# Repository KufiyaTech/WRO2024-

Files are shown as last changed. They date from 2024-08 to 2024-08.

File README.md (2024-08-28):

# Hi, we are KufiyaTech team , representing our beloved country , Palestine!
<p align="center">
  Palestine Flag
  &nbsp;&nbsp;&nbsp;&nbsp;
  Purpose Logo
</p>

This repository contains engineering materials of a self-driven vehicle's model participating in the WRO Future Engineers competition in the season 2024.

## Content

* `t-photos` contains 2 photos of the team (an official one and one funny photo with all team members)
* `v-photos` contains 6 photos of the vehicle (from every side, from top and bottom)
* `video` contains the video.md file with the link to a video where driving demonstration exists
* `schemes` contains one or several schematic diagrams in form of JPEG, PNG or PDF of the electromechanical components illustrating all the elements (electronic components and motors) used in the vehicle and how they connect to each other.
* `src` contains code of control software for all components which were programmed to participate in the competition
* `models` is for the files for models used by 3D printers, laser cutting machines and CNC machines to produce the vehicle elements. If there is nothing to add to this location, the directory can be removed.
* `other` is for other files which can be used to understand how to prepare the vehicle for the competition. It may include documentation how to connect to a SBC/SBM and upload files there, datasets, hardware specifications, communication protocols descriptions etc. If there is nothing to add to this location, the directory can be removed.

## READ.ME table of content

1. [Project Overview](#project-overview)

   1.1. [Competition Context](#competition-context)
   
   1.2. [Team Management](#team-management)

   1.3. [Strengths and Limitations of Our Vehicle](strengths-and-limitations-of-our-vehicle)   

2. [Programming Language and Libraries](programming-language-and-libraries)
   
   2.1. [Programming Language and Libraries](programming-language-and-libraries)
 
   2.2. [Detecting Turns and Direction](#detecting-turns-and-direction)
   
   2.3. [Lap Counting Method](#lap-counting-method)
   
   2.4. [IMU-Based Steering](#imu-based-steering)
   
3. [Open Challenge](#open-challenge-algorithm)

   3.1. [Open Challenge Overview](#open-challenge-overview)

   3.2. [PID Controller](#pd-controller)
   
   3.3. [Turn Execution](#turn-execution)
   
4. [Obstacle Avoidance Round Challenge](#obstacle-avoidance-round-challenge)

   4.1. [Obstacle Challenge Overview](#obstacle-challeng-overview)

   4.2. [Pillar Detection](#pillar-detection)
    
   4.3. [Obstacle Avoidance Strategy](#obstacle-avoidance-strategy)
   
5. [Designing Process](#designing-process)

   5.1. [Steering System](#steering-system)
    
   5.2. [Differential Gear](#differential-gear)
   
   5.3. [Chassis](#chassis)
   
   5.4. [Mechanism](#mechanism)
   
   5.5. [Ackermann Steering Mechanism](#ackermann-steering-mechanism)
   
6. [Power and Sense Management](#power-and-sense-management)

   6.1. [Power Source](#power-source)
    
   6.2. [Sensors We Used and Their Functions](#sensors-we-used-and-their-functions)
   
7. [Hurdles and Challenges](#hurdles-and-challenges)

   7.1. [Designing Process Challenges](#designing-process-challenges)
    
   7.2. [Sensor and Coding Challenges](#sensor-and-coding-challenges)

   7.3. [Mechanical Challenges](mechanical-challenges)

8. [Future Work](#future-work)

9. [Appendices](#appendices)

   9.1. [Datasheets and Specifications](#datasheets-and-specifications)
      
   9.2. [References](#references)

 10. [Reflections and Gratitude](#reflections-and-gratitude)

## Project Overview

This project has been in development for nearly three months to participate in the WRO Future Engineers 2024 competition. The competition challenges teams to develop a self-driving car capable of autonomously completing two rounds on a designated track. You can view the competition track here.

A self-driving car is a vehicle designed to operate with minimal to no human intervention. For this project, our focus has been on key areas such as sensor fusion, computer vision, and advanced control systems, which are critical to the vehicle's performance.

The project is aimed at engineering students, robotics enthusiasts, and anyone interested in autonomous vehicle technologies, especially those within the 14-19 age group. It incorporates a range of technologies, including C++, Arduino, and AI cameras for computer vision tasks.

The vehicle’s architecture features an Arduino-based control system, integrated with various sensors such as an IMU, ultrasonic sensors, and a camera. These components work together to achieve the desired level of autonomy.

To meet the competition’s demands, our approach integrates sophisticated hardware and software solutions. We’ve developed robust algorithms that enable the car to make autonomous decisions based on real-time sensor data. This not only demonstrates the car’s ability to avoid obstacles but also highlights its precision in following designated paths. The project spans multiple engineering disciplines, including electronics, mechanics, and software development, making it a comprehensive showcase of modern engineering applied to robotics.

### 1.1 Competition Context

The WRO Future Engineers 2024 competition challenges teams to design and develop autonomous vehicles capable of navigating a predefined course while executing specific tasks. This competition is structured across multiple rounds, including a practice round, two qualification rounds, and a final round, each progressively testing the vehicle's capabilities.

Participants must engineer their vehicles to handle complex challenges such as lane following, obstacle detection, and precise turning. The competition track is designed with a variety of elements, including straight paths, curves, and intersections, which the vehicle must navigate autonomously without human intervention. 

Scoring is based on the vehicle's ability to complete the course with accuracy and efficiency, with additional points awarded for successful task execution and speed.

For detailed competition rules, please refer to the official WRO Future Engineers 2024 guidelines: [WRO Future Engineers 2024 Rules](https://wro-association.org/wp-content/uploads/WRO-2024-Future-Engineers-Self-Driving-Cars-General-Rules.pdf)

### 1.2 Team Management

Our project is the result of a collaborative effort by a skilled and dedicated team, each member bringing unique expertise to the table. We are students of **Purpose Robotics Academy**, located in Ramallah, Palestine, where we have gained valuable skills in robotics and technology. You can learn more about the academy through their [website](https://purpose.ps/) and [Facebook page](https://www.facebook.com/PurposeEdu/).

- **Sara Jawaada**: As the lead designer, Sara was instrumental in overseeing the entire design process, ensuring that the physical and conceptual elements of the project were seamlessly integrated. Additionally, she played a key role in software development, contributing to both the architecture and implementation of core functionalities.

  **Contact Information**:  
  **Email**: [sarajawaada906@gmail.com](mailto:sarajawaada906@gmail.com)

- **Amro Duhaidi**: Amro led the technical implementation of the software, with a particular focus on sensor integration and system wiring. His expertise in coding and hardware interfacing was crucial in developing the responsive and reliable behavior of the robot, ensuring that all sensors were effectively utilized in the project's logic.

  **Contact Information**:  
  **Email**: [amro.duaidi@gmail.com](mailto:amro.duaidi@gmail.com)

**Project Supervisor**

We would like to extend our deepest gratitude to our mentor and coach, **Eng. Mohammad Muamar**. A distinguished engineer and graduate of Palestine Polytechnic University in Hebron, Eng. Muamar has been instrumental in guiding our team through every step of this competition. His dedication, expertise, and unwavering support have been invaluable to our progress and success.

As students of esteemed professors who are proud holders of Palestinian degrees with expertise of global standards, we are honored to have Eng. Muamar as our mentor. His commitment to excellence and his belief in our potential have profoundly shaped our approach and achievements in this project.

**Contact Information**:
- **Email**: [moh.mummar@gmail.com](mailto:moh.mummar@gmail.com)

**KufiyaTech Team's Social Accounts**

Stay connected with our team and follow our journey through our official social media channels. Explore more about our work, updates, and behind-the-scenes moments by visiting our link tree:

- **KufiyaTech Social Accounts**: [https://linktr.ee/kufiyatech](https://linktr.ee/kufiyatech)
- 
### 1.3. Vehicle Strengths and Limitations

**Strengths:**

- **Chassis and Mechanism:** We designed the chassis ourselves and incorporated a mechanism built using the LEGO kit. This approach not only ensures that the vehicle meets the competition’s specific requirements but also provides us with valuable hands-on experience in both design and engineering.

- **Lightweight and Fast**

**Limitations:**

- **Size**

- **Mechanism Precision**

**Vehicle Dimensions:**

-**Vehicle weight:** 980 gm

- **Without Camera:**
  - **Length:** 26 cm
  - **Width:** 16.7 cm
  - **Height:** 10.5 cm

- **With Camera:**
  - **Length:** 23 cm
  - **Width:** 16.7 cm
  - **Height:** 18 cm

## 2. Programming Language and Libraries

 **Programming Language**: **C++**

- **Why C++?**:

- We chose C++ because it is well-supported by the Arduino IDE and provides robust library support, making it an ideal choice for our project.
  
We leveraged several libraries to implement the functionalities required for our robot:

- **`Wire.h`**: Facilitates I2C communication between the Arduino and various sensors, such as the IMU, allowing us to efficiently gather and process sensor data.

- **`Servo.h`**: Used for controlling the servo motors, particularly in steering and managing precise movements.

- **`Pixy2.h`**: Handles communication with the Pixy2 camera sensor, which is crucial for visual tracking and object recognition tasks.

- **`MPU6050.h`**: Provides functions to interface with the MPU6050 IMU sensor, enabling accurate detection of orientation, acceleration, and gyroscopic data to manage the robot's movement and stability.

These libraries, combined with the robustness of C++, provide the necessary tools to implement the complex control logic required by our autonomous vehicle.

### 2.4 Detecting Turns and Direction

**Problem Statement:**
In the WRO Future Engineers competition, the direction of the car's movement is not predetermined; it can be either clockwise or counterclockwise. This unpredictability introduces an additional layer of complexity, particularly when the car needs to execute precise U-turns at specific points on the track. The challenge is to accurately detect the required direction and execute the turn with precision.

**First Solution: Using the TCS3200 Color Sensor**

One approach to solving this problem involved the use of the TCS3200 color sensor to detect the color-coded lines on the track that indicate the direction of the car's movement.

- **Color Detection:** The TCS3200 sensor was programmed to recognize specific colors on the track. An orange line signals that the car should move in a clockwise direction, while a blue line indicates a counterclockwise movement.

- **Controlled Turning:** Upon detecting a color, the car was instructed to turn at a specific angle. The turning angle was precisely controlled using an Inertial Measurement Unit (IMU), ensuring that the turn was executed accurately and consistently, regardless of external factors like speed or track conditions.

- **Code Implementation:** The process was automated through predefined functions such as `detectOrangeLine` and `detectBlueLine`, which triggered the appropriate turning actions based on the color detected.

This method provided a clear and direct way to determine the car's direction based on visual cues from the track, leveraging the IMU for precision in turning.

**Second Solution: Using Three Ultrasonic Sensors**

An alternative approach utilized three ultrasonic sensors to determine the direction of the car's movement based on distance measurements:

- **Direction Determination:** The ultrasonic sensors were positioned to monitor distances on the left, right, and front of the car. When the car reached a point where it needed to turn, the direction was determined by comparing the distances detected by the sensors:
  - If the distance measured by the right sensor was greater than that of the left sensor, the car would turn clockwise.
  - Conversely, if the left distance was greater, the car would turn counterclockwise.

- **Front Sensor Trigger:** Additionally, the front ultrasonic sensor played a crucial role by detecting when the car was approximately 50 cm away from an obstacle or turning point. This detection served as a cue for the car to initiate the turn.

This method relied on spatial awareness and distance measurement, allowing the car to make decisions based on its surroundings without relying on visual markers.

<p align="center">
  Turn Detection Logic
</p>
<p align="center">
  <em>Figure 1: Illustration of the turn detection logic using ultrasonic sensors.</em>
</p>

As illustrated above, when the car reaches the lines where it needs to turn, the direction of the turn is determined by the distance sensors. If the sensors detect that the right distance is greater than the left distance, the car should turn clockwise. If the left distance is greater than the right distance, the car will move counterclockwise. When the front sensor detects that the distance is approximately 50 cm, it indicates that the car should turn.

**Final Decision: Implementing the Ultrasonic Sensor-Based Approach**

After careful consideration, the "Kufiya" team decided to implement the second method using ultrasonic sensors. This decision was driven by numerous challenges encountered with the first method involving the color sensor. Despite spending two months attempting to fine-tune the color sensor, we faced significant issues with its accuracy, particularly in varying lighting conditions and with precise color recognition.

The sensor's inconsistent performance led to unreliable direction detection, which was critical for the success of our project. These difficulties prompted us to shift our focus to the ultrasonic sensor-based approach, which provided a more reliable and adaptable solution for determining the car's movement direction and executing precise turns.

### 2.5 Lap Counting Method

**Problem Statement:**
The goal is to implement a lap counting mechanism for an autonomous vehicle (or RC car) that accurately counts the number of laps the vehicle completes on a designated track. A key requirement is that after completing exactly three laps, the vehicle must automatically stop.

#### 1. Color Sensor-Based Detection

**Overview:**
The first method involves utilizing a color sensor (TCS3200) to detect specific markers placed on the track. This technique leverages the sensor's ability to identify distinct colors, allowing it to register a lap each time the sensor passes over a designated colored marker.

**Principle:**
- The color sensor is calibrated to recognize a specific color distinct from the track's surface.
- When the sensor detects this color, it triggers a signal to increment the lap count.

**Why Do We Not Recommend This Method?**

- **Accuracy Issues:** Despite extensive efforts, the color sensor consistently struggled to provide accurate readings, particularly with the color orange. Ambient lighting conditions significantly affected the sensor's performance, even with a custom shield.
- **Programming Challenges:** Programming the sensor to reliably identify the target color was difficult, especially given the high speed of the vehicle, which impaired the sensor’s ability to detect and register the color in real-time.
- **Unreliable Performance:** The sensor's inconsistent and imprecise measurements, especially under dynamic conditions, made it an unsuitable choice for our project. This unreliability led us to explore alternative lap counting methods.

#### 2.5 Loop-Based Counting with Ultrasonic Sensor and IMU

**Overview:**
The second method utilizes a software-based loop counter that increments the lap count each time a specific condition within the code is met. In our approach, the robot detects the completion of a lap using an ultrasonic sensor. When the sensor detects that the distance to a specific point or object is less than 50 cm, the robot recognizes this as an indicator to begin a new lap. The robot’s steering is controlled by an IMU (Inertial Measurement Unit), which ensures precise navigation during turns.

**Principle:**
- The loop-based method is implemented by continuously monitoring the distance using the ultrasonic sensor.
- When the sensor detects that the distance has decreased below 50 cm, the robot initiates a turning maneuver, guided by the IMU.
- This detection and turning process is managed within a loop structure in the code, specifically within a `while` loop that executes as long as the distance remains below 60 cm.
- Each time this condition is met, the program increments the lap count, allowing for accurate tracking of the robot’s laps.

**Advantages of This Method:**
- **Reliability:** This method provides more reliable lap counting, unaffected by external factors like ambient light.
- **Precision:** The IMU ensures precise control of the vehicle’s steering, contributing to accurate lap counting

---

### 2.6 IMU-Based Steering

**Overview:**

In our autonomous vehicle, precise steering control is essential for navigating the course accurately. We implemented an IMU-based steering mechanism to achieve this. The IMU (Inertial Measurement Unit) provides real-time data about the vehicle’s angular velocity, which is critical for calculating the yaw angle (the vehicle’s turning angle) and ensuring stable and accurate steering.

**Understanding the IMU:**

An IMU (Inertial Measurement Unit) is a sensor device that combines multiple sensing components, usually a 3-axis accelerometer and a 3-axis gyroscope. These sensors work together to track the vehicle's motion and orientation in three-dimensional space.

- **Accelerometer**: Measures the acceleration along the X, Y, and Z axes. It helps in determining the tilt of the vehicle.
- **Gyroscope**: Measures the angular velocity (the rate of rotation) around the X, Y, and Z axes. It is crucial for determining the vehicle's rotational motion, especially the yaw angle.

**The X, Y, and Z Axes:**

Understanding the axes is essential for interpreting the data provided by the IMU:

- **X-Axis**: Represents the roll, or the tilting motion of the vehicle from side to side.
- **Y-Axis**: Represents the pitch, or the tilting motion of the vehicle from front to back.
- **Z-Axis**: Represents the yaw, or the rotational movement of the vehicle around the vertical axis. This axis is crucial for steering, as it defines the direction the vehicle is facing.

<p align="center">
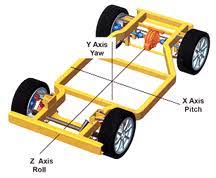
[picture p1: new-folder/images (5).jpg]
  
</p>
<p align="center"><em>*Figure 2: The X, Y, and Z axes relative to the vehicle.

**Calculating the Yaw Angle:**

The yaw angle (\(\theta_z\)) is a measure of the vehicle's rotation around the Z-axis. The gyroscope within the IMU provides angular velocity data along this axis, which tells us how quickly the vehicle is rotating.

To determine the vehicle's orientation or heading, we calculate the yaw angle by integrating the angular velocity over time. The yaw angle changes based on the rate of rotation, and by continuously updating this value, we can keep track of the vehicle's direction.

The equation used to calculate the yaw angle is:

<p align="center">
  Equation
</p>

<p align="center"><em>

Where:
- (theta_z) is the current yaw angle.
- (theta_{z, \text{previous}}\) is the yaw angle from the previous time step.
- ({gyro}_z\) is the angular velocity around the Z-axis (provided by the gyroscope).
- ({gyro\_z\_offset}\) is the gyroscope offset, calculated during calibration to correct any drift.
- (Delta t) is the time elapsed between the current and previous readings.

**Importance of Gyro Offset:**

The gyroscope offset (\(\text{gyro\_z\_offset}\)) is critical because gyroscopes can have slight errors or biases over time, known as drift. By calculating and subtracting this offset, we ensure that the yaw angle calculation is accurate and doesn't gradually deviate from the true value.

**PID Control for Steering:**

To maintain or correct the vehicle’s path, we implemented a PID (Proportional-Integral-Derivative) controller. The PID controller adjusts the steering angle based on the difference between the target yaw angle and the current yaw angle. This ensures smooth and stable steering.

## 3.Open Challenge 

### 3.1 Open Challenge Overview

The vehicle must complete three (3) laps on the track with random placements of the inside track walls

**Round objectives:**

•	Moving between the internal and external wall.

•	Turning the  car when detecting the lines . 

•	Detecting blue and orange lines on the mat.

•	Counting the laps.

•	The car stops after 3 laps. 

**Round constraints:**

•	Time.

•	The car Turning in the correct angle.

•	The direction of the car's movement is random.

•	The position from which the car starts moving is random.

•	The distance between the internal and external wall is random.

### 3.2 PID Controller

**Overview:**

The **PID (Proportional-Integral-Derivative) controller** is a widely used control loop feedback mechanism in industrial and automation systems. It is designed to continuously adjust a process to maintain the desired output, known as the setpoint, by minimizing the error between the setpoint and the actual process variable.

The PID controller operates by combining three distinct control actions:

1. **Proportional (P):** Reacts to the current error by producing an output that is proportional to the error. It provides immediate corrective action but can lead to overshoot if used alone.
2. **Integral (I):** Addresses accumulated past errors by summing them over time, helping to eliminate steady-state errors.
3. **Derivative (D):** Predicts future errors by considering the rate of change of the error, helping to reduce overshoot and oscillations.

The control signal, which is sent to the servo motor, is calculated as:

<p align="center">
  Equation 2
</p>

<p align="center"><em>

<div align="center">
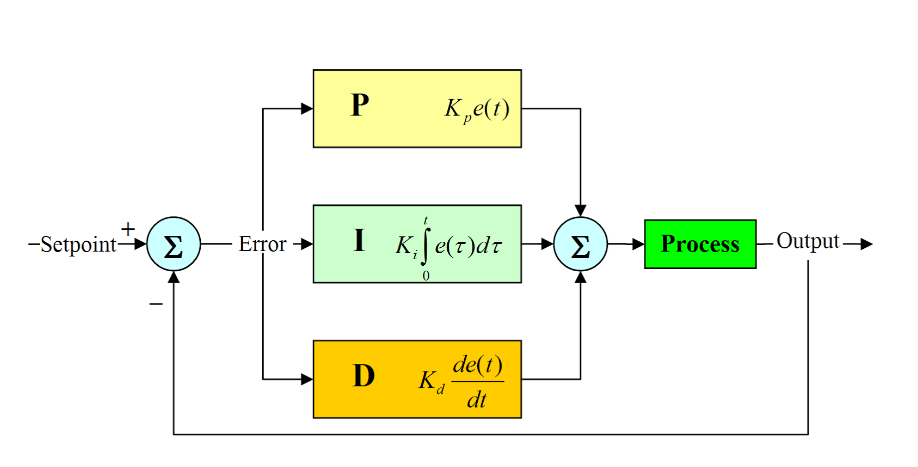
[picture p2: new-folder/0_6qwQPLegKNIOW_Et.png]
  
  <p><em>Figure 3: PID Control System for Steering.</em></p>
</div>

### Code Implementation:

The code implementation ties together the IMU readings, yaw angle calculation, and PID control to manage the vehicle's steering:

**Key Equations:**

**Proportional Term:**  

<div align="center">
  
  <p><em>Figure 4: The Proportional Term equation, where \( e(t) \) is the current error and \( K_p \) is the proportional gain.</em></p>
</div>

**Integral Term:**  

<div align="center">
  
  <p><em>Figure 2: The Integral Term equation, which sums past errors over time, multiplied by the integral gain \( K_i \).</em></p>
</div>

Here, `integral` is the accumulated error over time.

 **Derivative Term:**

<div align="center">
  
  <p><em>Figure 5: The Derivative Term equation, which considers the rate of change of the error, multiplied by the derivative gain \( K_d \).</em></p>
</div>

 **Combined PID Control:**

<div align="center">
  
  <p><em>Figure 6: The Combined PID Control equation that sums all three components to generate the control output.</em></p>
</div>

In our code:

- `error` is the difference between the target yaw angle (`targetYawAngle`) and the current yaw angle (`yaw_angle`).
- `integral` accumulates the `error` over time.
- `derivative` is the rate of change of the `error`.
- `controlSignal` is the final output applied to the servo motor, calculated using the combined PID equation.

- 
**Implementation in Our Project:**

In our autonomous vehicle project, the PID controller is utilized to maintain the vehicle's yaw angle, ensuring that it follows the desired path accurately.

**How It Works:**

1. **Initialization:**
   - The vehicle's IMU (Inertial Measurement Unit) is initialized to provide real-time gyroscope data. This data is crucial for determining the yaw angle, which represents the vehicle's direction.

2. **Error Calculation:**
   - The yaw angle error is calculated by comparing the current yaw angle with the target yaw angle. This error is then used to compute the necessary adjustments.
     ```cpp
     error = yaw_angle - targetYawAngle;
     ```

3. **PID Calculations:**
   - **Proportional:** The error is multiplied by the proportional gain \( K_p \) to determine the immediate correction.
   - **Integral:** The sum of past errors is calculated and multiplied by the integral gain \( K_i \), contributing to the correction by addressing accumulated deviations.
   - **Derivative:** The rate of change of the error is determined and multiplied by the derivative gain \( K_d \), providing a predictive adjustment to smooth out the response.
     ```cpp
     integral += error * (currentTime - previousTime);
     derivative = (error - previousError) / (currentTime - previousTime);
     ```

4. **Control Signal Generation:**
   - The control signal, which adjusts the servo motor's angle, is computed as the sum of the proportional, integral, and derivative components:
     ```cpp
     controlSignal = Kp * error + Ki * integral + Kd * derivative;
     float t = controlSignal + 90;
     t = constrain(t, 40, 140);
     myServo.write(int(t));
     ```

5. **Practical Application:**
   - As the vehicle moves, the PID controller continuously adjusts the steering to keep the vehicle on course. If the vehicle deviates, the controller calculates the necessary steering corrections to bring it back on track smoothly.

```cpp
#include <Wire.h>
#include <MPU6050.h>
#include <Servo.h>

MPU6050 mpu;
Servo myServo;
int16_t gz;
float yaw_angle = 0, gyro_z_offset = 0;
float Kp = 2, Ki = 0.001, Kd = 0.5;
float error, integral = 0, derivative, controlSignal;
unsigned long previousTime, currentTime;

void setup() {
    Serial.begin(9600);
    Wire.begin();
    mpu.initialize();
    myServo.attach(SERVO_PIN);
    Serial.println("Calibrating gyro...");
    calculateGyroDrift();
    Serial.println("Done Calibrating");
    previousTime = millis();
}

void loop() {
    MoveFWwithGyro();
}

void MoveFWwithGyro() {
    currentTime = millis();
    float elapsed_time = (currentTime - previousTime) / 1000.0;
    previousTime = currentTime;

    gz = mpu.getRotationZ() - gyro_z_offset;
    float gyro_z = gz / 131.0;
    yaw_angle += gyro_z * elapsed_time;

    error = targetYawAngle - yaw_angle;
    integral += error * elapsed_time;
    derivative = (error - previousError) / elapsed_time;
    controlSignal = Kp * error + Ki * integral + Kd * derivative;
    controlSignal = constrain(controlSignal, 40, 140);
    myServo.write(int(controlSignal));

    previousError = error;
    Serial.print("Yaw Angle: "); Serial.println(yaw_angle);
}

void calculateGyroDrift() {
    for (int i = 0; i < 2000; i++) {
        gyro_z_offset += mpu.getRotationZ();
        delay(2);
    }
    gyro_z_offset /= 2000;
}
```

**Explanation of the Code:**

1. **Setup:**
   - The IMU and servo motor are initialized. The gyroscope is calibrated to calculate the `gyro_z_offset`.
   
2. **Main Loop:**
   - The function `MoveFWwithGyro()` is called continuously. It reads the gyroscope data, calculates the yaw angle, and then computes the control signal using the PID controller.
   
3. **Yaw Angle Calculation:**
   - The yaw angle is updated based on the angular velocity around the Z-axis, factoring in the time elapsed since the last update.
   
4. **PID Control:**
   - The error between the desired and actual yaw angle is calculated. The control signal, which adjusts the steering angle, is then determined by the PID formula. This control signal is sent to the servo motor to adjust the vehicle's direction.

**Conclusion:**

The PID controller is a critical component in our system, ensuring the vehicle maintains a stable and accurate trajectory. By balancing the immediate response (P), accumulated error correction (I), and predictive adjustment (D), the PID controller allows for precise control of the vehicle's movements, even in dynamic and challenging environments.

### 3.2 Turn Execution

To ensure the car turns efficiently when reaching U-turns, we applied precise control for accurate turn execution.

**Turn Execution Logic**

The process of executing turns integrates several key components to achieve precision and reliability:

1. **Ultrasonic Sensors**:
   - Our vehicle is equipped with ultrasonic sensors on the left, right, and front sides, which continuously provide distance measurements from walls.
   - These sensors play a crucial role in determining the need and direction of the turn by comparing the distances detected on either side of the vehicle.

2. **Gyroscope (Inertial Measurement Unit - MPU6050)**:
   - The IMU sensor provides real-time data on the vehicle's yaw angle, which is the rotational angle around the vertical axis.
   - This data is essential for calculating the vehicle's current orientation and ensuring that turns are executed with high angular precision.

3. **PID Controller**:
   - To ensure smooth and controlled turning, a Proportional-Integral-Derivative (PID) controller is used.
   - The PID controller calculates the difference between the current yaw angle and the target yaw angle, adjusting the steering motor accordingly.
   - This control mechanism is critical in avoiding overshooting or undershooting the turn, maintaining the vehicle's intended path.

**Code Implementation for Turn Execution**

The following code snippet demonstrates the logic and functions used to manage turn execution:

```cpp
void MoveFWwithGyro() {
    long current_time = millis();
    currentTime = millis();
    float elapsed_time = (current_time - previous_time) / 1000.0;
    previous_time = current_time;

    gz = mpu.getRotationZ();
    gz -= gyro_z_offset;
    float gyro_z = gz / 131.0;
    yaw_angle += gyro_z * elapsed_time;

    error = yaw_angle - targetYawAngle;
    integral += error * elapsed_time;
    derivative = (error - previousError) / elapsed_time;
    controlSignal = Kp * error + Ki * integral + Kd * derivative;
    float t = controlSignal + 90;

    t = constrain(t, 50, 130);
    myServo.write(int(t));

    previousError = error;
    previousTime = currentTime;

    Serial.print("Yaw Angle: "); Serial.println(yaw_angle);
}

void TurnRight() {
    targetYawAngle -= 89; // Adjust this value for sharper or softer turns
    while (yaw_angle > targetYawAngle + 5) {
        MoveFWwithGyro();
    }
}

void TurnLeft() {
    targetYawAngle += 89; // Adjust this value for sharper or softer turns
    while (yaw_angle < targetYawAngle - 5) {
        MoveFWwithGyro();
    }
}
```

**Overview of Operations**

**Turn Initiation:**

- The robot initiates a turn  when the track requires a change in direction, such as a U-turn.
- The turn direction is determined by comparing the distance readings from the left and right sensors, ensuring that the vehicle turns in the optimal direction.

**Turn Execution:**

- The `MoveFWwithGyro()` function is the core routine that continuously monitors the vehicle's orientation and adjusts the steering angle during the turn.
- Depending on the required turn direction, the `TurnRight()` or `TurnLeft()` function sets the target yaw angle and engages the PID-controlled steering adjustments until the vehicle reaches the desired orientation.
- The PID controller plays a critical role in minimizing error and stabilizing the vehicle's movement during and after the turn.
- 
**Post-Turn Adjustment:**

- Once the vehicle achieves the required yaw angle, the steering mechanism returns the vehicle to a straight path, allowing it to continue its course efficiently.
- The combination of real-time sensor data and the PID control algorithm ensures that the vehicle resumes its path without deviation or drift.

By integrating advanced sensor data and control algorithms, our vehicle is capable of executing turns with high precision, a crucial capability for successfully navigating the competition track.

## 4. Obstacle Avoidance Round Challenge

**Obstacle Challenge Overview**

In this challenge, the autonomous vehicle must complete three laps on a track where green and red traffic signs are randomly placed. These signs instruct the vehicle on which side of the lane it should follow:

- **Red Pillar**: Indicates that the vehicle must stay on the right side of the lane.
- **Green Pillar**: Indicates that the vehicle must stay on the left side of the lane.

At the end of the second lap, the final traffic sign will determine the direction for the third lap:

- **Green Traffic Sign**: The vehicle continues the third lap in the same direction.
- **Red Traffic Sign**: The vehicle must turn around and complete the third lap in the opposite direction.

The vehicle is required not to move any of the traffic signs during the course. After completing all three laps, the vehicle must find the designated parking area and perform parallel parking.

**Important Note**: The initial driving direction (clockwise or counterclockwise) will change in different rounds of the challenge. Both the starting position of the vehicle and the number and location of traffic signs are randomly set before each round begins.

**Round Objectives**

- **Traffic Sign Response**: 
  - **Red Pillar**: Steer right.
  - **Green Pillar**: Steer left.

- **Third Lap Direction**:
  - **Green Sign**: Continue in the same direction.
  - **Red Sign**: Reverse direction.

- **Turn Execution**: 
  - Turn when reaching the U-TURN.

- **Lane Keeping**: 
  - Stay centered between the walls.

- **Final Task**: 
  - Perform parallel parking after completing three laps.

**Round constraints:**

- Randomized Pillar Placement
- Randomized Pillar Count
- Randomized Driving Direction
- Randomized Starting Position
- Randomized Parking Lot Location
.

### 4.2 Pillar detection 

**Pixy2 Camera Overview**

Pixy2 is a compact, fast, and versatile vision sensor specifically designed for robotics applications. Like its predecessor, Pixy2 can quickly learn to detect objects that you teach it, simply by pressing a button. It also features advanced algorithms for detecting and tracking lines, which is particularly useful for line-following robots. These algorithms can even detect intersections and recognize "road signs" that can instruct your robot to perform actions like turning left, turning right, or slowing down. All of this is processed at 60 frames-per-second, ensuring that your robot can operate at high speeds while still accurately detecting its environment.

For more details, you can visit the [Pixy2 Official Website](https://pixycam.com/pixy2/) and check out this [informative video](https://www.youtube.com/watch?v=391dXDjqzXA&t=1675s) on how to use Pixy2. Additionally, if you want to learn more about teaching Pixy2 to recognize objects, you can refer to the [Pixy2 Documentation](https://docs.pixycam.com/wiki/doku.php?id=wiki:v2:teach_pixy_an_object_2).

**Example of Pixy2 in Action**

We configured the Pixy2 camera using the PixyMon application to detect green and red pillars. Below are images captured from the PixyMon interface, showing the successful detection of these objects:

<div align="center">
  <table>
    <tr>
      <td align="center" style="padding: 10px;">
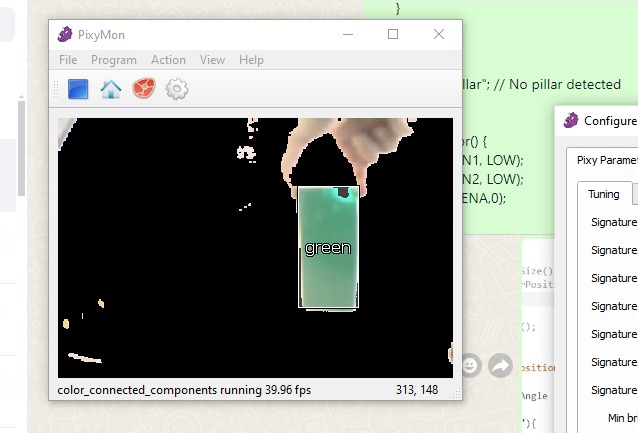
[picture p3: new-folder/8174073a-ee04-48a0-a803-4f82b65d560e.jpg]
Pixy2 Detecting Green Object
        <br>
        <figcaption><strong>Figure 7:</strong> Pixy2 camera detecting a green object.</figcaption>
      </td>
      <td align="center" style="padding: 10px;">
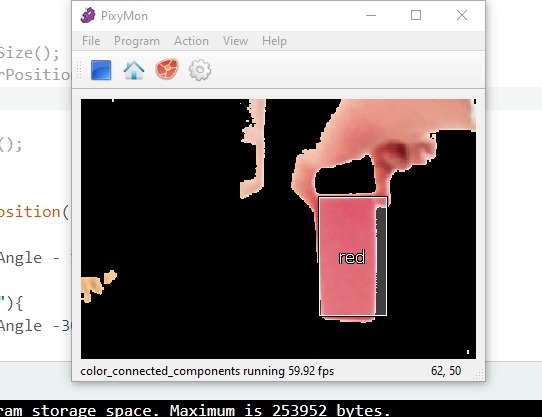
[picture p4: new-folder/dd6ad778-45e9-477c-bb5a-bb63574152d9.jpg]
Pixy2 Detecting Red Object
        <br>
        <figcaption><strong>Figure 8:</strong> Pixy2 camera detecting a red object.</figcaption>
      </td>
    </tr>
  </table>
</div>

### 4.3 Obstacle Avoidance Strategy

In the Obstacle Avoidance Round, the vehicle employs the Pixy2 camera to detect pillars on the track. The logic behind the code ensures that the vehicle reacts appropriately based on the detected pillars’ size and color:

- **Pillar Detection**: The Pixy2 camera continuously scans for pillars along the vehicle’s path. Once a pillar is detected, the system measures its size to determine if it is relevant for further action.

- **Size Check**: If the detected pillar's size is greater than 1000, the vehicle proceeds to analyze its color. This size threshold helps filter out irrelevant objects or distant pillars that do not require an immediate response.

- **Color-Based Reaction**:
  - **Green Pillar**: If the pillar is green, the vehicle is programmed to make a left turn. This is achieved by adjusting the servo motor's angle to steer the vehicle in the correct direction.
  - **Red Pillar**: Conversely, if the pillar is red, the vehicle makes a right turn by similarly adjusting the servo motor's angle.

This process ensures that the vehicle navigates the track effectively by responding to the obstacles in its path with precise and controlled movements.

### 5. Designing Process

Building an RC car for the WRO Future Engineers competition from scratch has been a significant challenge, especially since it was our first time designing a robot. Although using a kit would have been an easier option, we were committed to building our own robot, which left us with no other options. As we began gathering the necessary components, our focus was on identifying the exact mechanisms required for our RC car. Our goal was to solve the challenges presented in the two competition rounds as effectively and simply as possible. The design of our robot has evolved over time, and here is how our designs have developed throughout this journey:

#### 5.1 Steering System

- *First Design:*
  - Our initial steering system was functional, but we faced challenges in supporting and securing all the components on top of it.
 <p align="center">
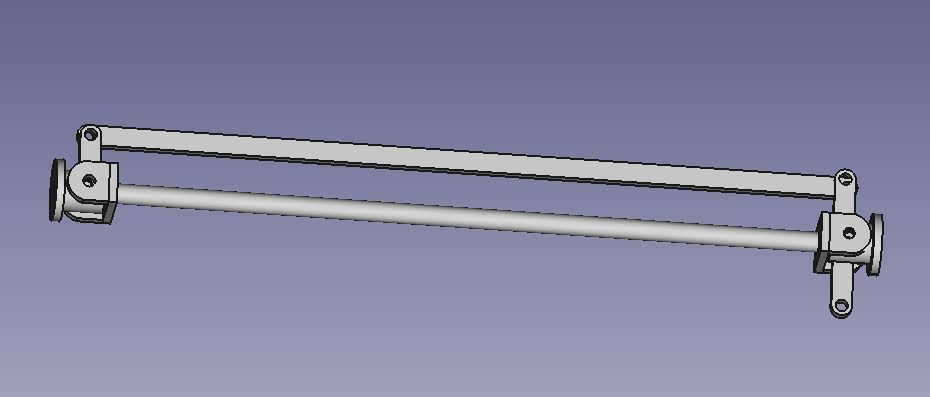
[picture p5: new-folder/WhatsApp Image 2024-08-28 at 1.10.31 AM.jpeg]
First Steering System Design
  
</p>
<p align="center"><em>Figure 9: First Steering System Design</em></p>

- *Second Design:*
  - This design proved to be a better choice initially, but it was based on ready-to-print files sourced from the internet. This presented a dilemma: adhere to the predefined dimensions that we couldn't alter, or undertake the challenge of designing it entirely from scratch.
  - *Link 1:* [3D Printed RC Car with Brushless Motor](https://cults3d.com/en/3d-model/gadget/3d-printed-rc-car-with-brushless-motor-lee3d999)

- *Third Design:*
  - Unlike our previous designs, this iteration did not require 3D printing because we utilized the EV3 LEGO kit for the mechanism. This approach saved us time and effort, providing the flexibility to modify and control it easily. The LEGO kit offered a reliable steering solution that we could test quickly, contrasting with the longer process required by our previous designs.

#### 5.2 Differential Gear System

- *First Design:*
  - Our initial choice was similar to the second steering system option in terms of using ready-to-print files. However, we encountered familiar challenges, compounded by an additional difficulty: the inability to locate suitable shafts or bearings within our allotted timeframe.
 
  - *Link 2:* [3D Printed RC Car with Brushless Motor](https://cults3d.com/en/3d-model/gadget/3d-printed-rc-car-with-brushless-motor-lee3d999)

- *Second Design:*
  - In this design, we chose to utilize the EV3 LEGO system to construct our steering mechanism, marking a departure from our previous approaches. This choice offered the same advantages as our third steering system design, particularly in terms of ease of management and reliability.

#### 5.3 Chassis Design Process

- *First Design:*
  - Our initial design phase was the most time-consuming. Being our first attempt, we struggled with defining the shape of our robot and determining how it would accommodate all intended components, including five ultrasonic sensors. This constrained our design options significantly. Our primary objective was to create a chassis capable of housing all components, prioritizing functionality over minimizing size. We positioned the camera at the rear without adhering to standard engineering principles. Initially, we planned to use a 3D printer for manufacturing.
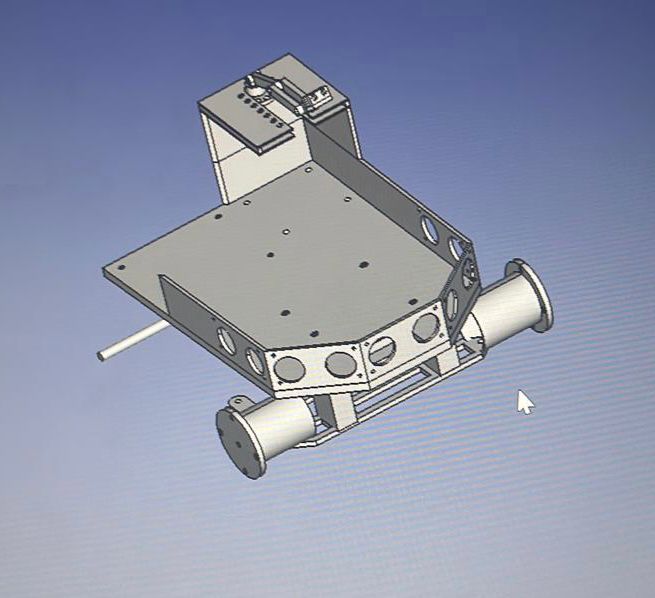
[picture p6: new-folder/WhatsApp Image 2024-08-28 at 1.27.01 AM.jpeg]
First Chassis Design
  -

  - **Figure 11**: First Chassis Design

- *Second Design:*
  - This was the first design we brought to life by printing it using a 3D printer. This design incorporated our chosen mechanism, but upon completion, we discovered it was too compact to meet our established standards.
 <p align="center">
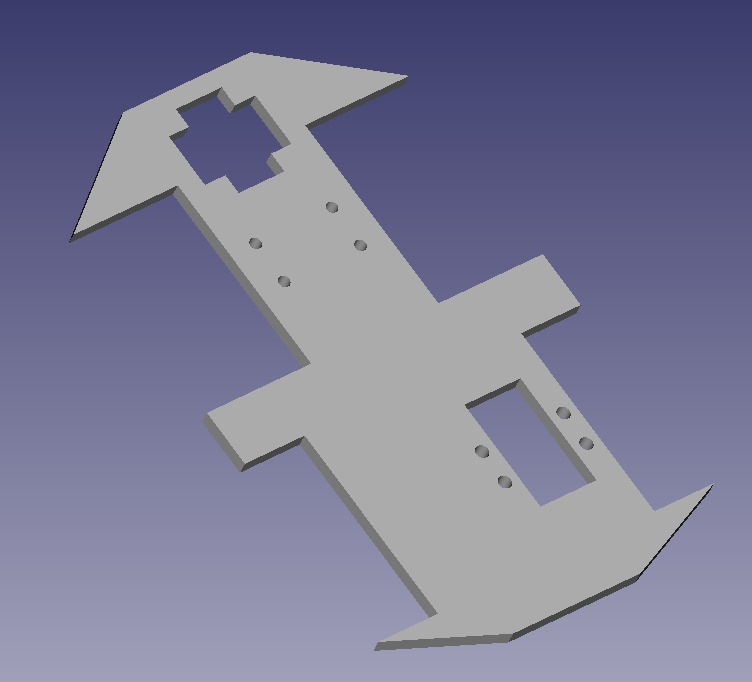
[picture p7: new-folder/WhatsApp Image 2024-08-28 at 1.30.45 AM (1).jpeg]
Second Chassis Design
  
</p>

- **Figure 12:** Second Chassis Design

*Third Design:*
  - Before proceeding with the computer-aided design, we sketched our third design on paper. We then crafted a prototype using compressed cork to evaluate its dimensions. Our aim was to slightly increase its size while accommodating our chosen mechanisms. However, due to limitations with our printer, we were compelled to design two separate bases (chassis) and join them together. During testing, we discovered a potential vulnerability: the structure could potentially break apart under specific weight conditions.

<p align="center">
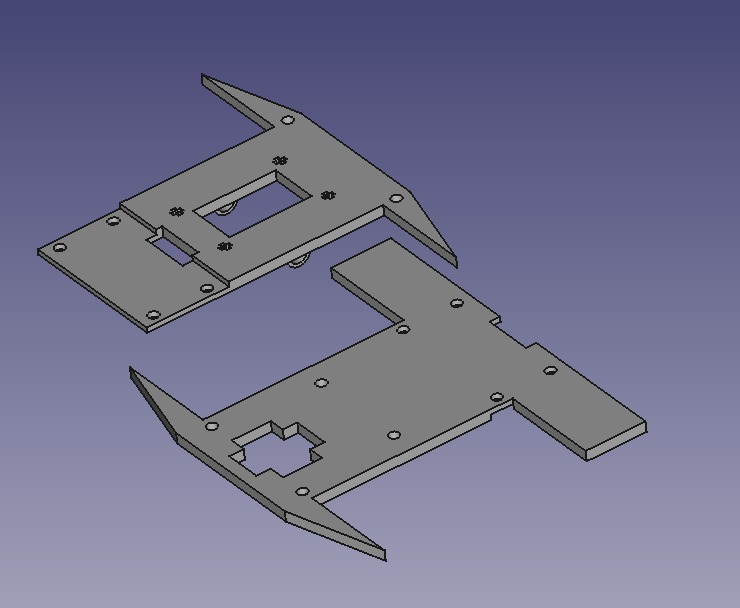
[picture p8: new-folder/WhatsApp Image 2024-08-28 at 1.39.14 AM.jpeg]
Third Chassis Design - Front View
  
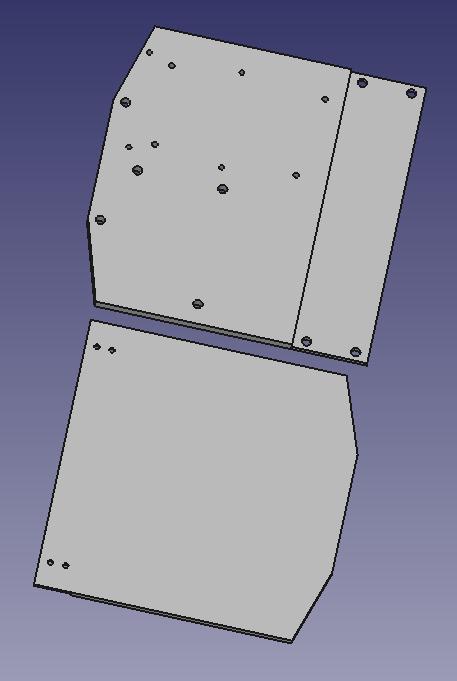
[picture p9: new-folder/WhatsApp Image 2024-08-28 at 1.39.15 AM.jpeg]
Third Chassis Design - Side View
  
</p>

<p align="center"><strong>Figure 13:</strong> Third Chassis Design - Front and Side Views</p>

- *Fourth Design:*
  - We decided to shift from using a 3D printer to a CNC machine for bringing our designs to reality. This allowed us to create a single, connected chassis capable of supporting more weight. Our design continued to evolve due to changes in our mechanism and component choices. A significant change was opting for smaller LEGO wheels to improve steering, which took some time to perfect. Another challenge we faced was managing space constraints relative to the size of our mechanisms. However, with the guidance and support of our coach, we were able to find better solutions and overcome these obstacles. After deciding to use a CNC machine, we encountered several challenges in selecting the ideal material to meet our needs. Initially, we chose acrylic, but it proved too brittle and broke easily. We then selected wood, which met our goals and requirements perfectly.

  - If you are interested in viewing the detailed designs, please check the `models` directory in the repository.

#### 5.4 Mechanism

- *Rear-Wheel Drive (RWD):*
  - Our vehicle’s drivetrain works with the engine to deliver power to the wheels. We utilized a rear-wheel drive system, where the engine's power is directed to the rear wheels. This system provided balanced weight distribution and higher control over the vehicle. The rear-wheel drive system consisted of several main components: the drive shaft, the rear axle, and the differential gears, which in turn transmitted the power to the axles and then to the wheels. Our car's mechanism was constructed using the LEGO EV3 kit.

#### 5.5 Ackermann Steering Mechanism

- We used the Ackermann steering geometry, a configuration designed to ensure that the wheels of a vehicle trace out circles with different radii during a turn, preventing tire slippage. This geometry helps align the front wheels towards the turning center, providing improved handling and stability, especially at low speeds. It contrasts with other mechanisms like the Davis steering gear, offering simpler construction and fewer components susceptible to wear. Ackermann steering is commonly used in standard vehicles for its advantages in maneuverability and reduced tire wear.
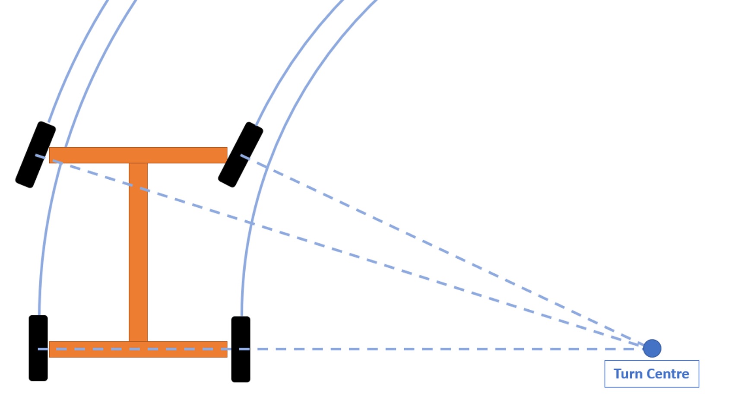
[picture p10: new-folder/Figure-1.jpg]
Ackermann Steering Mechanism
 - 
  - Figure 14: Ackermann Steering Mechanism

## 6.Power and Sense management 
## 6. Power and Sense Management

### 6.1 Power Source

#### Power Source: Why We Chose a 12V Lithium-ion Battery

**Overview:**

Lithium-ion batteries are a top choice in robotics due to their high energy density, lightweight design, and ability to deliver high currents. These features make them ideal for applications requiring both power and mobility, such as our autonomous robot.

**Advantages of Lithium-ion Batteries:**

1. **High Energy Density:** Lithium-ion batteries provide a high amount of energy in a small, lightweight package, which is critical for keeping the robot agile while providing enough power for all components.
2. **High Discharge Rate:** They can supply the high current needed to drive motors and other power-hungry components effectively.
3. **Lightweight and Compact:** Their design allows for easy integration into the robot without adding unnecessary bulk.
4. **Stable Voltage Output:** Ensures consistent performance of the robot's components, which is crucial for maintaining reliable operation.

**Why a 12V Battery?**

- **Voltage Compatibility:**
  - The 12V output is ideal for many robotics components, such as motors and motor drivers, which are designed to operate efficiently at this voltage. This minimizes the need for complex voltage conversion, simplifying the power distribution system.
  
- **Power Sufficiency:**
  - A 12V battery provides ample power for the entire robot, ensuring that high-demand components like motors receive enough voltage while still allowing for efficient voltage regulation down to 5V or 3.3V for other electronics.

**Key Characteristics of the 12V Lithium-ion Battery:**

- **Voltage:** 12V nominal, ideal for direct use with motors and for stepping down to lower voltages.
- **Capacity:** Typically 6600mAh, affecting how long the robot can operate before needing a recharge.
- **Discharge Rate:** High C-ratings (e.g., 20C) ensure the battery can supply the necessary current for motors and other components during peak usage.
- **Weight:** Lightweight design, typically around 150g for a 2200mAh battery, crucial for maintaining the robot’s agility.

**Choosing the Perfect Power Supply for Your Robot:**

When selecting a power supply or battery for your robot, consider the following factors:

- **Energy Requirements:** Assess the total power needs of your robot, including motors, sensors, and control units. Choose a battery that can provide sufficient voltage and current for all components.
  
- **Battery Type:** Lithium-ion batteries are often the best choice for robotics due to their high energy density and discharge rates. However, also consider other options like NiMH based on your specific requirements.

- **Voltage and Capacity:** Ensure the battery’s voltage matches the requirements of your highest voltage components, and its capacity (mAh) is sufficient to provide long operating times without frequent recharges.

- **Weight and Size:** The battery should be lightweight and compact to fit within your robot’s design without adding excessive weight that could affect performance.

- **Safety Features:** Choose batteries with built-in protection against overcharging, overheating, and short circuits to ensure the safety and longevity of your robot.

The 12V Lithium-ion battery was selected for our robot because it offers the best balance of power, efficiency, and weight. It provides the necessary voltage to power all components, from high-demand motors to sensitive electronics, ensuring the robot operates reliably and efficiently. By understanding the energy requirements and choosing a battery that meets these needs, we ensure that our robot remains powerful, agile, and safe.

### Power Distribution from the 12V Lithium-ion Battery to Each Component

In our autonomous robot, the power distribution system is crucial to ensure that each component receives the correct voltage for optimal operation. The 12V Lithium-ion battery serves as the primary power source, and through a carefully designed distribution system, we step down and regulate the voltage to match the requirements of different sensors, controllers, and motors. Below, we provide a detailed explanation of how the 12V power is distributed to each component, accompanied by diagrams to visualize the power flow.

**1. Power Source: 12V Lithium-ion Battery**

The 12V Lithium-ion battery provides a stable and sufficient voltage supply for the entire system. It’s selected for its high energy density, stable output, and ability to handle high discharge rates, which are essential for driving motors and powering sensors and controllers.

**2. Voltage Regulation and Distribution**

Given the diverse voltage requirements of the components in our robot, we use voltage regulators and the motor driver to distribute the 12V power efficiently:

- **A. Direct 12V Supply to High-Voltage Components**

  - **L298N Motor Driver:**
    - The L298N Motor Driver directly utilizes the 12V supply to drive the motors. The motor driver is capable of handling the 12V input and converts it to the necessary output to control the DC motors.
    - **Reason:** The motors require higher voltage for effective operation, and the L298N motor driver is designed to manage this directly from the 12V source.

- **B. Step-Down Voltage for Low-Voltage Components**

  - **5V Regulated Supply for Microcontroller and Sensors:**
    - **Voltage Regulator:** A 12V to 5V voltage regulator is used to step down the voltage for components that require a 5V input, such as the Arduino Mega 2560, HC-SR04 Ultrasonic Sensors, and the MPU-6050 IMU.
    - **Components Powered:**
      - **Arduino Mega 2560:** The Arduino Mega is the main microcontroller that controls all operations of the robot. It operates at 5V, hence the regulated 5V supply is essential.
      - **HC-SR04 Ultrasonic Sensors:** These sensors measure distance using ultrasonic waves and also operate at 5V.
      - **MPU-6050:** This sensor module, which includes an accelerometer, gyroscope, and magnetometer, operates at 3.3V, so an additional step-down regulator might be used if needed.
    - **Reason:** These components require lower voltage for operation, and supplying them with 12V could damage them. The regulator ensures a stable 5V output.

**3. Power Flow Diagram**

To visualize the power distribution, here’s a simplified flowchart showing how the 12V Lithium-ion battery's power is divided:

```plaintext
[12V Lithium-ion Battery]
       |
       |---> [L298N Motor Driver] ---> Motors (12V)
       |
       |---> [12V to 5V Voltage Regulator] 
                   |---> [Arduino Mega 2560] (5V)
                   |---> [HC-SR04 Ultrasonic Sensors] (5V)
                   |---> [MPU-6050] (5V)
                   |---> [Pixy2 Camera] (5V)
```
**For a more detailed Lithium ion safety manual, you can refer to the following resources:**
- [MIT Lithium Battery Safety Guidance](https://ehs.mit.edu/wp-content/uploads/2019/09/Lithium_Battery_Safety_Guidance.pdf)

### 6.2 Bill of materials (BOM)

| **Component** | **Quantity** | **Fu-nction/Purpose** |
|---|---|---|
| **Arduino Mega 2560** | 1 | Main microcontroller board that controls all operations of the robot. |
| **L298N Motor Driver** | 1 | Controls the direction and speed of the DC motors using PWM signals. |
| **MG995 Servo Motor** | 1 | Provides precise angular position control for steering mechanisms. |
| **HC-SR04 Ultrasonic Sensors** | 3 | Measures distance to obstacles; placed at the front, left, and right sides of the robot for obstacle detection. |
| **12V Lithium Rechargeable Battery** | 1 | Provides the primary power source for all components. |
| **Pixy2 Camera** | 1 | Detects and tracks pillars (red and green) and helps in navigation by identifying road signs. |
| **MPU-6050 IMU** | 1 | Measures orientation and stabilizes the car’s steering for smooth and efficient turns. |
| **HW083 Voltage Regulator** | 1 | Steps down the 12V input to 5V and 3.3V to power various sensors and the microcontroller. |
| **Jumper Cables** | - | Used to connect various components together on the breadboard. |
| **Wheels** | 4 | Allows the car to move; driven by the DC motors. |
| **DC Motors** | 1 | Powers the wheels to drive the car forward, backward, and turn. |

**Suppliers**

We sourced our electronic components from the following suppliers, all based in Palestine. These suppliers deliver across the West Bank:

- [HIT Electronic Store](https://hit.ps/)
- [RoboticX Store](https://roboticx.ps/)
- [Labco Ramallah](https://www.facebook.com/labco.Ramallah/?locale=ar_AR)

## 7.Hurdles and Challenges
### 7.1. Designing Process Challenges

**1. Component Selection and Layout:**
   - We faced challenges in selecting compatible components and placing them efficiently within the robot's compact design. Ensuring all parts fit without overcrowding was a significant issue.

**2. Cable Management:**
   - Managing and securing the wiring was difficult. Cables frequently broke or disconnected when the robot hit obstacles, leading to unreliable connections and functionality.

**3. Prototyping and Iteration:**
   - The design underwent multiple revisions due to various issues, such as improper component placement and structural weaknesses. Each prototype revealed new challenges, requiring adjustments and improvements.

**4. Dimension and Fit Issues:**
   - We encountered problems with the robot's dimensions, leading to misalignment and cramped spaces for components. This necessitated redesigning the layout to ensure everything fit properly.

**5. Material Selection:**
   - Choosing the right material for the robot's structure was difficult. Initial materials were too fragile, causing breakages. After testing several options, we settled on wood for its strength and durability.

### 7.2. Sensor and Coding Challenges

#### TCS3200 Color Sensor

- **Challenge: Inconsistent Color Detection**
  - **Problem:** The TCS3200 color sensor struggled with accurately detecting the orange color, particularly under varying lighting conditions. Despite extensive calibration efforts, the sensor's readings remained unreliable, impacting the robot's ability to differentiate between colors accurately, which was critical for task completion.
  - **Approach:** We conducted several tests in controlled environments, adjusting the ambient light and altering the sensor's positioning. Additionally, multiple software filters were applied to stabilize the sensor's output.
  - **Result:** Despite these efforts, the sensor continued to underperform in distinguishing orange from similar hues. This led us to explore alternative sensors.
  - **Reference:** [TCS3200 Datasheet](https://www.mouser.com/catalog/specsheets/tcs3200-e11.pdf)

#### MPU-6050 IMU

- **Challenge: Gyroscope Drift and Accuracy**
  - **Problem:** The MPU-9250, which combines a gyroscope, accelerometer, and magnetometer, exhibited significant drift over time, leading to inaccuracies in the robot's orientation and steering control. This drift made it difficult to maintain stable and precise movements, especially during prolonged operations.
  - **Approach:** We implemented a rigorous calibration routine to minimize offset errors and employed complementary filtering to combine data from the accelerometer and gyroscope, thereby reducing the impact of drift over time. Below is a snippet of the PID control algorithm used to correct the robot's steering based on IMU data.
  - **Code Snippet:**
    ```cpp
    // Complementary filter implementation
    yaw_angle += gyro_z * elapsed_time;
    error = yaw_angle - targetYawAngle;
    integral += error * elapsed_time;
    derivative = (error - previousError) / elapsed_time;
    controlSignal = Kp * error + Ki * integral + Kd * derivative;
    myServo.write(constrain(controlSignal + 90, 40, 140));
    previousError = error;
    ```
  - **Result:** The adjustments led to a significant improvement in the robot's navigation stability, although some minor drift remained. This experience underscored the importance of sensor fusion techniques in robotics.
  - **Reference:** [MPU-6050 Datasheet and specification ](https://invensense.tdk.com/wp-content/uploads/2015/02/MPU-6000-Datasheet1.pdf)

#### First-Time Experience with Arduino and Sensors

- **Challenge: Steep Learning Curve with New Hardware and Software**
  - **Problem:** This project marked our first experience with Arduino, C++, and the sensors we utilized. We faced challenges in understanding the communication protocols, particularly I2C for the IMU and PWM for the servo motor, which led to initial integration difficulties.
  - **Approach:** We relied heavily on online resources, including official Arduino documentation, community forums, and GitHub repositories, to troubleshoot issues and enhance our understanding of sensor integration. Practical experimentation and iterative testing were crucial in overcoming these obstacles.
  - **Outcome:** Through this process, we not only resolved the immediate issues but also gained substantial experience and confidence in working with embedded systems and microcontroller programming. This learning experience has been invaluable for our future projects.
  - 
### 7.3. Mechanical Challenges

 **1. Stability Issues with the Mechanism**

- **Challenge: Lack of Stability in the Mechanism**
  - **Problem:** The initial design of our robot's mechanism faced significant stability issues. The instability was particularly evident in the differential and servo components, where precise movements were critical but not consistently achieved.
  
- **Servo Motor Accuracy:**
  - **Problem:** The servo motor we initially used was not accurate enough to maintain consistent control over the mechanism. This lack of precision led to erratic movements and contributed to the overall instability of the robot.
  - **Solution:** To address this, we bypassed the gears and connected the servo motor directly. However, this solution was only partially effective, as it did not fully resolve the issue of precision.

- **Differential Gear Issues:**
  - **Problem:** The differential gears were another source of instability. Initially, we used LEGO gears, but these proved to be problematic. The LEGO gears were not securely fitting together, causing them to slip frequently and fail to transmit power effectively.
  - **Solution:** To overcome this, we designed and 3D-printed custom couplers and gears. These custom parts were specifically designed to fit together securely and provide the necessary stability and power transmission required for the robot's differential.

- **Outcome:**
  - The custom 3D-printed gears and couplers significantly improved the stability and reliability of the mechanism. By designing parts that were tailored to our specific needs, we were able to eliminate the issues caused by the original LEGO gears and ensure that the robot's movements were precise and consistent.

## 8. Future Work

We have plans to redesign the vehicle to reduce its size, enhancing its maneuverability on tight and complex tracks. This will allow the vehicle to perform better in various challenges. Additionally, we aim to improve the mechanism to increase overall performance and efficiency, ensuring that the vehicle meets the demands of future competitions effectively.

## 9.Appendices
### 9.1. Datasheets and Specifications

Below are the datasheets for each of the key components used in the project:

| **Component** | **Datasheet Link** |
|---|---|
| **Arduino Mega 2560** | [View Datasheet](https://docs.arduino.cc/resources/datasheets/A000067-datasheet.pdf) |
| **L298N Motor Driver** | [View Datasheet](https://www.handsontec.com/dataspecs/L298N%20Motor%20Driver.pdf) |
| **MG995 Servo Motor** | [View Datasheet](https://www.alldatasheet.com/html-pdf/1132435/ETC2/MG995/109/1/MG995.html) |
| **HC-SR04 Ultrasonic Sensor** | [View Datasheet](https://cdn.sparkfun.com/datasheets/Sensors/Proximity/HCSR04.pdf) |
| **pixy2 camera** | [View Datasheet](https://media.digikey.com/pdf/Data%20Sheets/Seeed%20Technology/102991074_Web.pdf) |
| **MPU-6050 IMU** | [View Datasheet](https://invensense.tdk.com/wp-content/uploads/2015/02/MPU-6000-Datasheet1.pdf) |

### 9.2. References
Below are the references used throughout the project documentation:
1. [PID Control](https://medium.com/autonomous-robotics/pid-control-85596db59f35) - A detailed guide on PID control in robotics.

2. [Proportional-Derivative (PD) Controller](https://electronicscoach.com/proportional-derivative-controller.html) - Explanation of the PD controller and its applications.

3. [When and Why to Use P, PI, PD, and PID Controllers](https://medium.com/@svm161265/when-and-why-to-use-p-pi-pd-and-pid-controller-73729a708bb5) - An overview of different types of controllers and their uses.

4. [LiPo Battery Safety Warnings](https://power.tenergy.com/lipo-safety-warnings/) - Important safety information about using LiPo batteries.

5. [World Robot Olympiad - Future Engineers](https://world-robot-olympiad-association.github.io/future-engineers-gs/) - Guidelines and resources for participating in the World Robot Olympiad.
  
6. [Getting Started with the HC-SR04 Ultrasonic Sensor](https://projecthub.arduino.cc/Isaac100/getting-started-with-the-hc-sr04-ultrasonic-sensor-7cabe1) - A guide to using the HC-SR04 Ultrasonic Sensor with Arduino.

7. [Controlling DC Motor with Arduino Motor Shield Rev3](https://docs.arduino.cc/tutorials/motor-shield-rev3/msr3-controlling-dc-motor/) - An Arduino tutorial on controlling a DC motor using the Motor Shield Rev3.

## 10. Reflections and Gratitude

Over the past three months, we've worked closely together as a team, under the dedicated supervision of our mentor, Eng. Mohammad Muamar. His unwavering support, both technically and morally, has been invaluable throughout this journey. We are deeply grateful for his guidance and the time he invested in helping us reach our goals.

This experience has been a remarkable one for each of our three team members. We ventured into new areas of technology, learning not just the technical aspects but also the importance of time management, teamwork, and the collective spirit needed to succeed.

We would also like to extend our heartfelt thanks to the organizers of this competition. Their efforts in creating such a challenging and inspiring event have provided us with an opportunity to grow, learn, and apply our skills in a real-world context.

This competition has been an unforgettable journey, teaching us lessons that extend far beyond the challenges we faced. We look forward to carrying these lessons forward in our future endeavors.

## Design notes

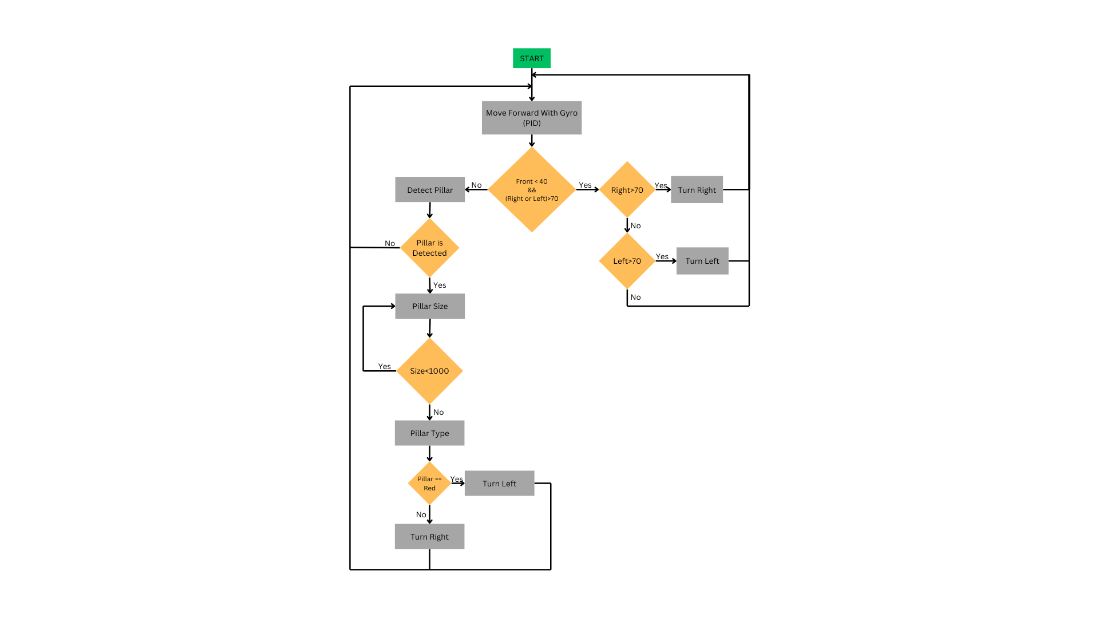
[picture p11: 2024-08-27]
other/FLOWCHART.png

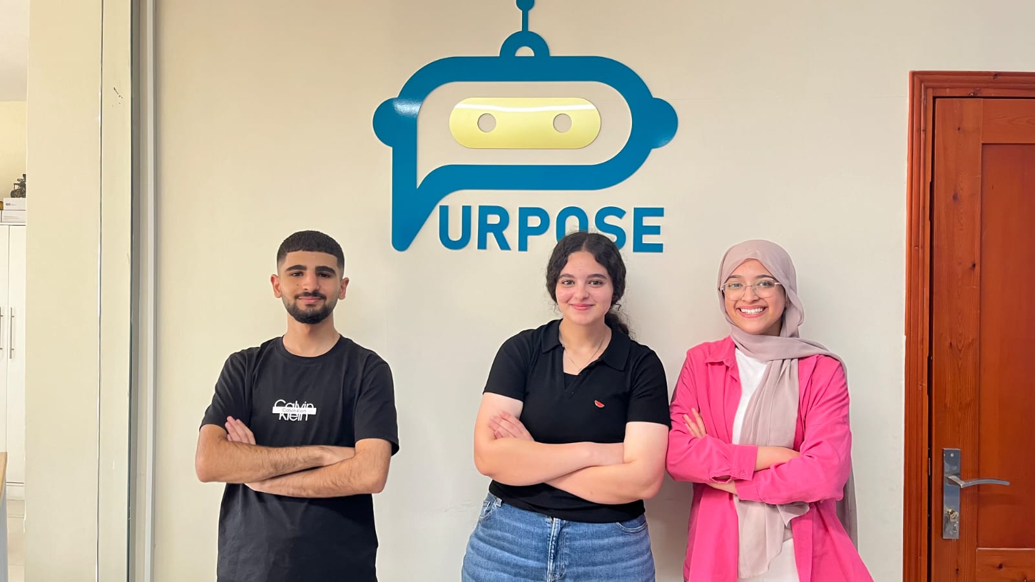
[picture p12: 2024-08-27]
t-photos/t-Photo.jpg

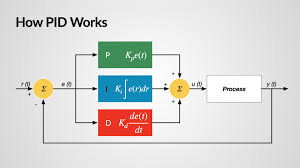
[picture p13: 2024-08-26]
new-folder/images (6).jpg

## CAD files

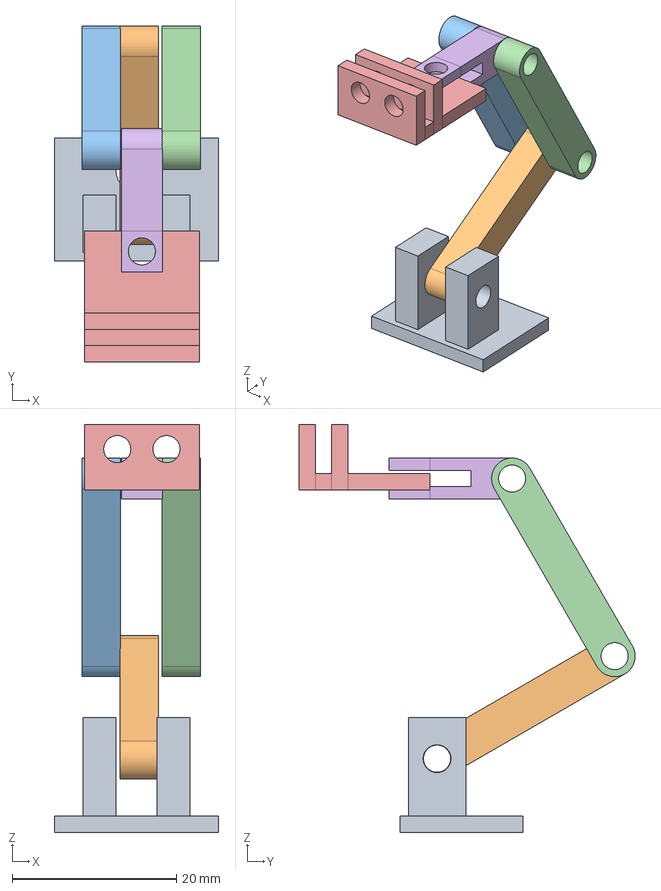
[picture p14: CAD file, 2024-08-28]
models/Cam_Assembly.FCStd
20.0 x 41.0 x 49.7 mm
BASE-033_001
CAM-03_001
CAM-03_002
CAM-03_003
CAM-04_001
CAM-02_001

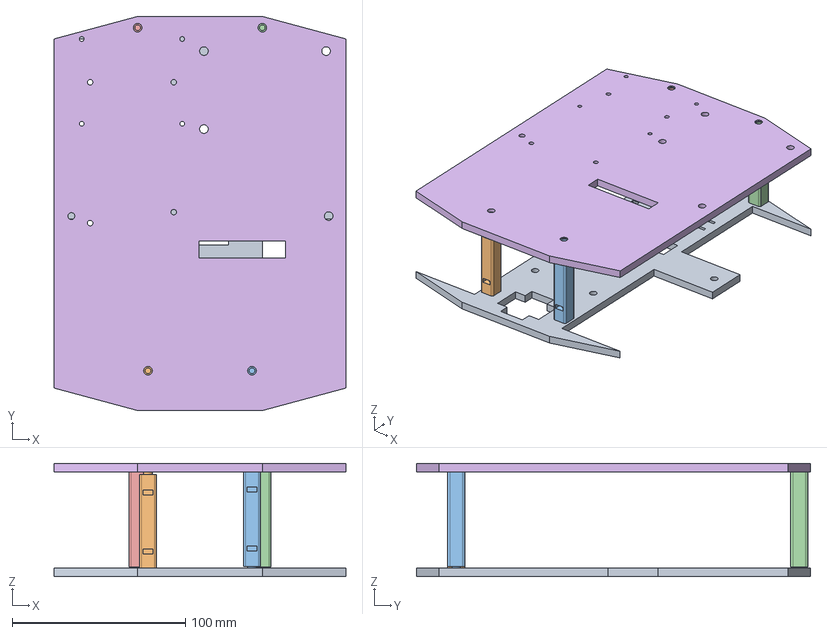
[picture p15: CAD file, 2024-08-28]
models/Frame_Assembly.FCStd
168.6 x 227.5 x 65.4 mm
str-01_001
str-02_001
str-02_002
str-02_003
str-02_004
str-03_001

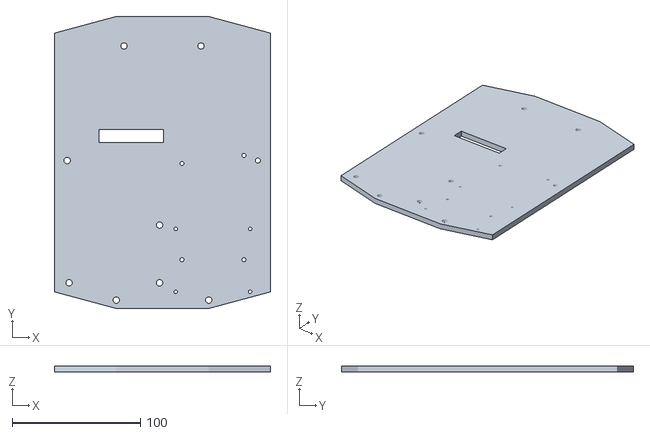
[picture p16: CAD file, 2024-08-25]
models/BASE-02.stl
168.6 x 227.5 x 5.00

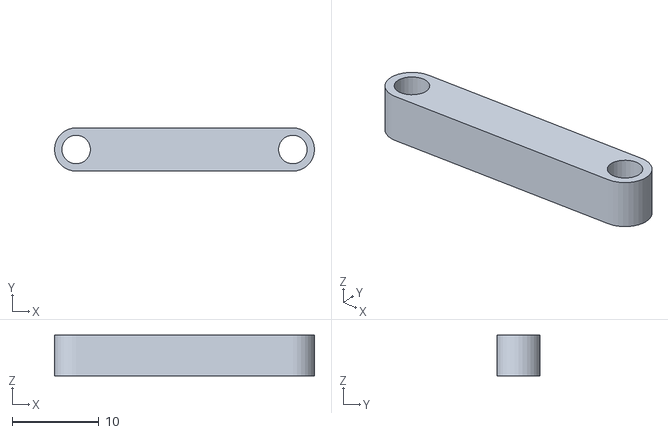
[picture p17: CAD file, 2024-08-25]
models/BASE-05.stl
30.0 x 5.00 x 4.70

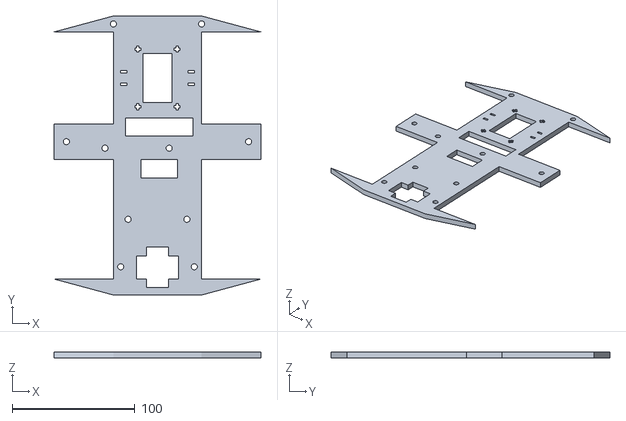
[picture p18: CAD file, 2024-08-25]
models/BASE-01.stl
168.6 x 227.5 x 5.00

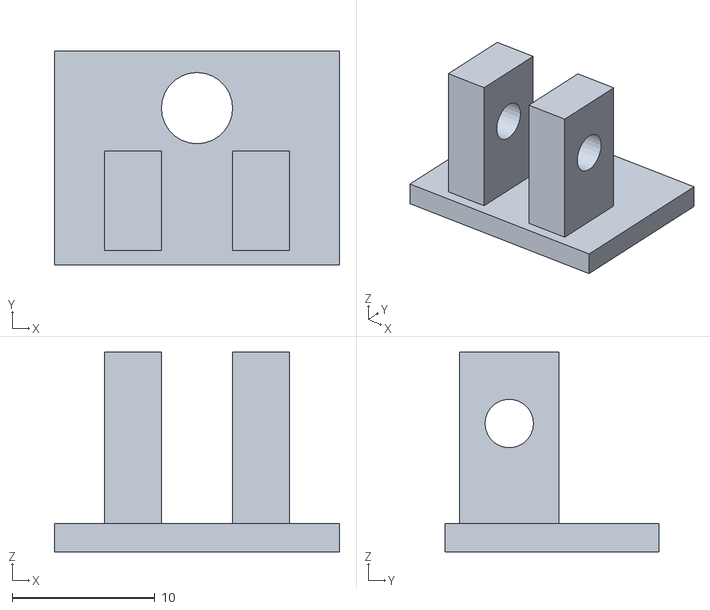
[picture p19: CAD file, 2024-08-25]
models/BASE-07.stl
20.0 x 15.0 x 14.0

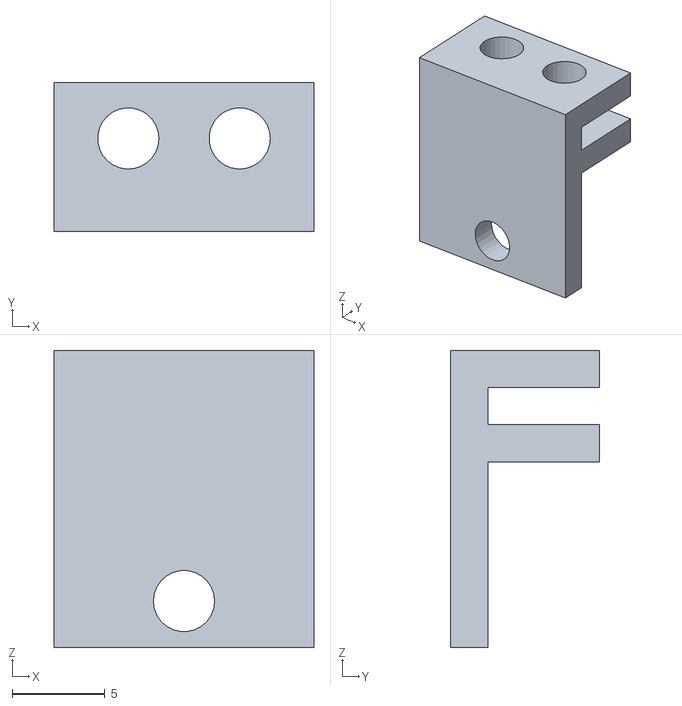
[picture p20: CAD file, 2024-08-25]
models/BASE-06.stl
14.0 x 8.00 x 16.0

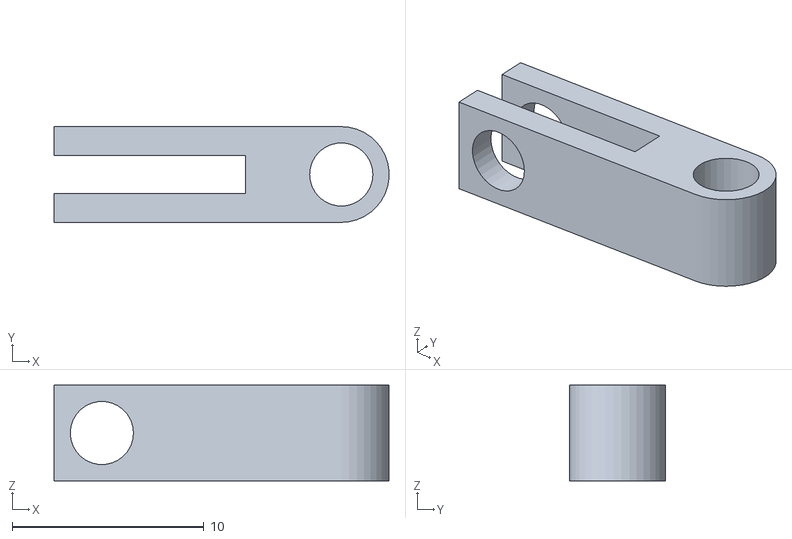
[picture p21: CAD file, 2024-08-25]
models/BASE-04.stl
17.5 x 5.00 x 5.00

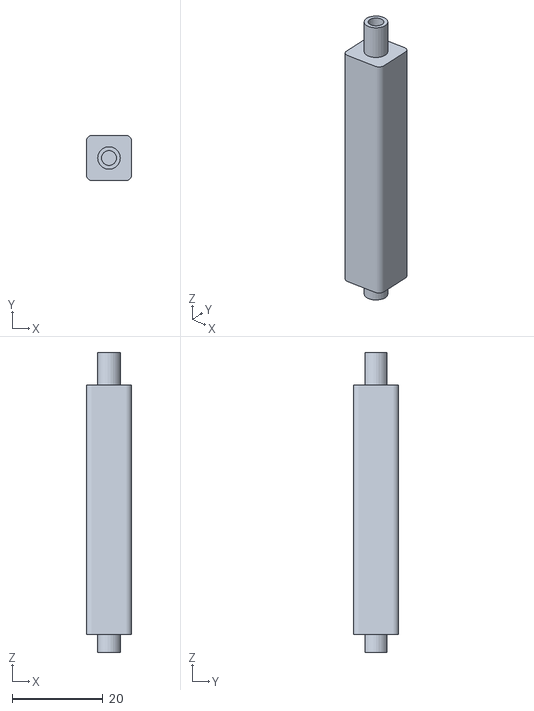
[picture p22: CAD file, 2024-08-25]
models/BASE-03 (1).stl
10.0 x 10.0 x 66.2

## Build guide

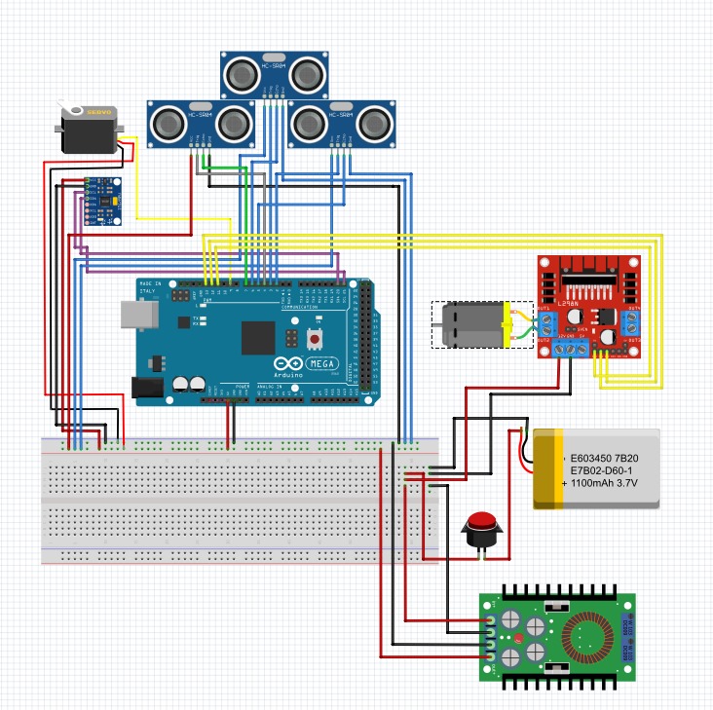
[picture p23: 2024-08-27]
schemes/Wiring_diagram1.jpeg

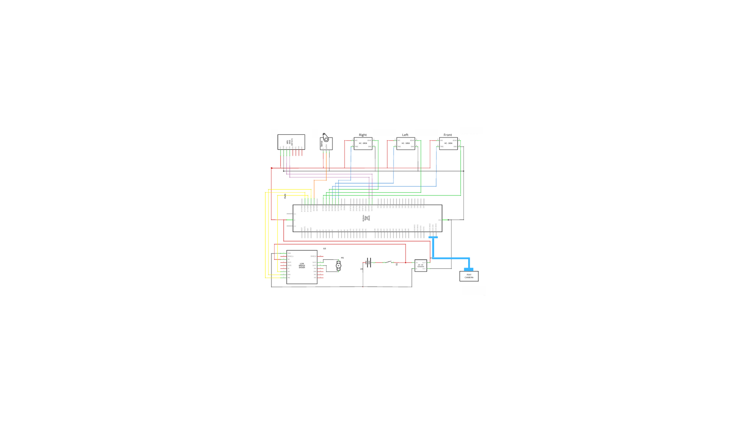
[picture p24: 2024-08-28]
schemes/wiringdiagram2.png

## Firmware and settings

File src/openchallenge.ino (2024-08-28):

#include <Wire.h>
#include <MPU6050.h>
#include <Servo.h>

// .....................................Pin Definitions...........................................//
#define SERVO_PIN 9
#define INITIAL_ANGLE 90
#define IN1 11
#define IN2 12
#define ENA 13
#define trigPinl 3
#define echoPinl 6
#define trigPinr 2
#define echoPinr 5
#define trigPinf 4
#define echoPinf 7

MPU6050 mpu;
Servo myServo;

//.........................................variables.............................................//
int16_t gz;
long previous_time;
float yaw_angle = 0;
float gyro_z_offset = 0;
int calibration_count = 2000;                         // Number of samples for calibration
int currentAngle = INITIAL_ANGLE;

unsigned long lastTime = 0;
int i = 0; 
int targetYawAngle = 0;

// PID parameters
float Kp = 1.5;
float Ki = 0.01;
float Kd = 0.5;
// PID variables
float error;
float controlSignal;

int steering_angle  = 89 ;
int c = 0;
int turn_count = 0; // Number of turns

void setup() {
    // ..................................Initialization........................................//
  Serial.begin(9600);
  Wire.begin();
  mpu.initialize();
    // ..................................Motor Driver setup......................................//
  pinMode(IN1, OUTPUT);
  pinMode(IN2, OUTPUT);
  pinMode(ENA, OUTPUT);
  
  //................................. Ultrasonic sensor setup..................................//
  pinMode(trigPinl, OUTPUT);
  pinMode(echoPinl, INPUT);
  pinMode(trigPinr, OUTPUT);
  pinMode(echoPinr, INPUT);
  pinMode(trigPinf, OUTPUT);
  pinMode(echoPinf, INPUT);
  //.............................Check if MPU6050 is connected properly.......................//
  Serial.println(mpu.testConnection() ? "MPU6050 connected" : "MPU6050 connection failed");
  //.............................Calibrate the gyro to calculate drift........................//
    myServo.attach(SERVO_PIN);
  myServo.write(currentAngle);
  Serial.println("Calibrating gyro...");
  calculateGyroDrift();
  Serial.println("Done Calibrating");
  //.......................................Servo setup.......................................//


  digitalWrite(IN1, HIGH);  // Set direction
  digitalWrite(IN2, LOW);   // Set direction
  analogWrite(ENA, 0);      // Set initial speed (0-255)

  //...................................... Main code .......................................//
  previous_time = millis(); // Record the start time


  while (usForward() > 80 || (usRight() < 70 && usLeft() < 70 )) { 
    MoveFWwithGyro();
    analogWrite(ENA, 255); 
  }
  while (usForward() > 60 || (usRight() < 70 && usLeft() < 70 )) { 
    MoveFWwithGyro();
    analogWrite(ENA, 220); 
  }
  analogWrite(ENA, 0);  
  delay(100);
  
  //....... Determine the Direction of Rotation .......//
  if (usLeft() < usRight()) {  // Clockwise (CW)
    i = 1; 
  } else if (usLeft() > usRight()) { // Counterclockwise (CCW)
    i = 2;
  } else {
    while (1) {
     myServo.write(30);
     delay(1000);
     myServo.write(160);
     delay(1000);
    }
  }
  analogWrite(ENA, 255);
  while (i == 1) {
    analogWrite(ENA, 255);
    MoveFWwithGyro();
    
    if (usForward() < 60 && usRight() > 100) {
      c = 0;
      targetYawAngle -= 90;
      while (c<2000) {
        MoveFWwithGyro();
        c = c+1;
      }
      
      turn_count++; // Increment the turn count
      if (turn_count >= 12) { // Check if 12 turns have been made
        delay(100); // Delay for 1 second before stopping
        analogWrite(ENA, 0); // Stop the robot
        while (1); // Stop permanently
      }
    }
  }

  while (i == 2) {
    MoveFWwithGyro();
    if (usForward() < 60 && usLeft() > 100) { 
      targetYawAngle += 89;
      c=0;
      while (c < 1500) {
        MoveFWwithGyro();
        c=c+1;
      }

      turn_count++; // Increment the turn count
      if (turn_count >= 12) { // Check if 12 turns have been made
        delay(100); // Delay for 1 second before stopping
        analogWrite(ENA, 0); // Stop the robot
        while (1); // Stop permanently
      }
    }
  }
}

void loop() {
  //MoveFWwithGyro();
}

// .....................................Functions Definitions...........................................//
//........... Moving forward with Gyro Feedback ...........//
void MoveFWwithGyro() {
    long current_time = millis();
    
    float elapsed_time = (current_time - previous_time) / 1000.0; // Calculate elapsed time in seconds
    previous_time = current_time;

    // Get the Z-axis rotation value
    gz = mpu.getRotationZ();

    // Apply drift correction
    gz -= gyro_z_offset;

    // Convert gyroscope reading to degrees per second
    float gyro_z = gz / 131.0;

    // Calculate the yaw angle by integrating the angular velocity over time
    yaw_angle += gyro_z * elapsed_time;
    error = yaw_angle - targetYawAngle;

  // Calculate the control signal
  controlSignal = Kp * error;

    float t = controlSignal + 90;

    t = constrain(t, 50, 135);   // Keep the angle within bounds
    myServo.write(int(t));
}


void yaw() {
  long current_time = millis();
  float elapsed_time = (current_time - previous_time) / 1000.0; // Calculate elapsed time in seconds
  previous_time = current_time;

  // Get Z-axis rotation value
  gz = mpu.getRotationZ();

  // Apply drift correction
  gz -= gyro_z_offset;

  // Convert gyroscope reading to degrees per second
  float gyro_z = gz / 131.0;

  // Calculate the yaw angle by integrating the angular velocity over time
  yaw_angle += gyro_z * elapsed_time;
}

//................. Gyro Calibration ....................//
void calculateGyroDrift() {
  for (int i = 0; i < calibration_count; i++) {
    // Get Z-axis rotation value
    gz = mpu.getRotationZ();
    gyro_z_offset += gz;
    delay(2); // Short delay between readings to stabilize
  }
  // Average the readings to get the drift (offset) value
  gyro_z_offset /= calibration_count;
}

//................. Ultrasonic....................//
long getUltrasonicDistance(int trigPin, int echoPin) {
  // Trigger the ultrasonic sensor
  digitalWrite(trigPin, LOW);
  delayMicroseconds(2);
  digitalWrite(trigPin, HIGH);
  delayMicroseconds(10);
  digitalWrite(trigPin, LOW);

  // Read the echo pin
  long duration = pulseIn(echoPin, HIGH);

  // Calculate the distance in cm
  long distance = duration * 0.034 / 2;

  return distance;
}

long usLeft() {
  return getUltrasonicDistance(trigPinl, echoPinl);
}

long usRight() {
  return getUltrasonicDistance(trigPinr, echoPinr);
}

long usForward() {
  return getUltrasonicDistance(trigPinf, echoPinf);
}

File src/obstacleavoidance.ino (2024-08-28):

#include <Wire.h>
#include <MPU6050.h>
#include <Servo.h>
#include <Pixy2.h>

// Pin Definitions
#define SERVO_PIN 9
#define INITIAL_ANGLE 90
#define IN1 11
#define IN2 12
#define ENA 13
#define trigPinl 3
#define echoPinl 6
#define trigPinr 2
#define echoPinr 5
#define trigPinf 4
#define echoPinf 7

MPU6050 mpu;
Servo myServo;
Pixy2 pixy;

// Variables
int16_t gz;
long previous_time;
float yaw_angle = 0;
float gyro_z_offset = 0;
int calibration_count = 2000;  // Number of samples for calibration
int currentAngle = INITIAL_ANGLE;
unsigned long lastTime = 0;
int targetYawAngle = 0;

// PID parameters
float Kp = 1.5;
float Ki = 0.01;
float Kd = 0.5;
// PID variables
float error;
float previousError = 0;
float integral = 0;
float derivative;
float controlSignal;
unsigned long previousTime;
unsigned long currentTime;

void setup() {
  Serial.begin(9600);
  Wire.begin();
  pixy.init();
  mpu.initialize();
  
  // Motor Driver setup
  pinMode(IN1, OUTPUT);
  pinMode(IN2, OUTPUT);
  pinMode(ENA, OUTPUT);
  
  // Ultrasonic sensor setup
  pinMode(trigPinl, OUTPUT);
  pinMode(echoPinl, INPUT);
  pinMode(trigPinr, OUTPUT);
  pinMode(echoPinr, INPUT);
  pinMode(trigPinf, OUTPUT);
  pinMode(echoPinf, INPUT);
  
  // Check if MPU6050 is connected properly
  Serial.println(mpu.testConnection() ? "MPU6050 connected" : "MPU6050 connection failed");
  
  // Calibrate the gyro to calculate drift
  Serial.println("Calibrating gyro...");
  calculateGyroDrift();
  Serial.println("Done Calibrating");
  
  // Servo setup
  myServo.attach(SERVO_PIN);
  myServo.write(currentAngle);

  digitalWrite(IN1, HIGH);  // Set direction
  digitalWrite(IN2, LOW);   // Set direction
  analogWrite(ENA, 0);      // Set initial speed (0-255)

  previous_time = millis(); // Record the start time
}

void loop() {
  MoveFWwithGyro();

  if (detectPillar()) {
    int size = calculatePillarSize();
    if (size <= 1000) {  // If the pillar is within the acceptable size range to handle
      avoidPillar();
    }
  }

  if (usForward() < 40 && (usRight() > 70 || usLeft() > 70)) {
    if (usRight() > 70) {
      turnRight();
    } else if (usLeft() > 70) {
      turnLeft();
    }
  }
}

void avoidPillar() {
  int pillarType = detectPillar();
  if (pillarType == 2) { // Red pillar
    turnRightAroundPillar();
  } else if (pillarType == 4) { // Green pillar
    turnLeftAroundPillar();
  }
}

void turnRightAroundPillar() {
  // Change the robot's angle by a small amount to move around the pillar
  targetYawAngle -= 30; 
  int c = 0;
  while (c < 1000) {
    MoveFWwithGyro();
    c++;
  }
  
  // Return the robot to the original path
  targetYawAngle += 30; 
  c = 0;
  while (c < 1000) {
    MoveFWwithGyro();
    c++;
  }
}

void turnLeftAroundPillar() {
  // Change the robot's angle by a small amount to move around the pillar
  targetYawAngle += 30;
  int c = 0;
  while (c < 1000) {
    MoveFWwithGyro();
    c++;
  }
  
  // Return the robot to the original path
  targetYawAngle -= 30;
  c = 0;
  while (c < 1000) {
    MoveFWwithGyro();
    c++;
  }
}

// Functions Definitions

// Move forward with Gyro Feedback
void MoveFWwithGyro() {
  long current_time = millis();
  currentTime = millis();
  float elapsed_time = (current_time - previous_time) / 1000.0; // Calculate elapsed time in seconds
  previous_time = current_time;

  // Get the Z-axis rotation value
  gz = mpu.getRotationZ();

  // Apply drift correction
  gz -= gyro_z_offset;

  // Convert gyroscope reading to degrees per second
  float gyro_z = gz / 131.0;

  // Calculate the yaw angle by integrating the angular velocity over time
  yaw_angle += gyro_z * elapsed_time;
  error = yaw_angle - targetYawAngle;

  // Calculate integral and derivative
  integral += error * (currentTime - previousTime);
  derivative = (error - previousError) / (currentTime - previousTime);

  // Calculate the control signal
  controlSignal = Kp * error + Ki * integral + Kd * derivative;

  float t = controlSignal + 90;

  t = constrain(t, 50, 135);   // Keep the angle within bounds
  myServo.write(int(t));

  previousError = error;
  previousTime = currentTime;
}

// Gyro Calibration
void calculateGyroDrift() {
  for (int i = 0; i < calibration_count; i++) {
    gz = mpu.getRotationZ();
    gyro_z_offset += gz;
    delay(2); // Short delay between readings to stabilize
  }
  gyro_z_offset /= calibration_count;
}

// Ultrasonic Sensor Functions
long getUltrasonicDistance(int trigPin, int echoPin) {
  digitalWrite(trigPin, LOW);
  delayMicroseconds(2);
  digitalWrite(trigPin, HIGH);
  delayMicroseconds(10);
  digitalWrite(trigPin, LOW);

  long duration = pulseIn(echoPin, HIGH);

  long distance = duration * 0.034 / 2;

  return distance;
}

long usLeft() {
  return getUltrasonicDistance(trigPinl, echoPinl);
}

long usRight() {
  return getUltrasonicDistance(trigPinr, echoPinr);
}

long usForward() {
  return getUltrasonicDistance(trigPinf, echoPinf);
}

// Pillar Detection Functions
int detectPillar() {
  pixy.ccc.getBlocks();

  if (pixy.ccc.numBlocks) {
    for (int i = 0; i < pixy.ccc.numBlocks; i++) {
      if (pixy.ccc.blocks[i].m_signature == 2) {
        Serial.println("Red pillar detected");
        return 2; // Red pillar detected
      } else if (pixy.ccc.blocks[i].m_signature == 4) {
        Serial.println("Green pillar detected");
        return 4; // Green pillar detected
      }
    }
  }
  
  return 0; // No pillar detected
}

int calculatePillarSize() {
  pixy.ccc.getBlocks();

  if (pixy.ccc.numBlocks) {
    for (int i = 0; i < pixy.ccc.numBlocks; i++) {
      if (pixy.ccc.blocks[i].m_signature == 2 || pixy.ccc.blocks[i].m_signature == 4) {
        return pixy.ccc.blocks[i].m_width * pixy.ccc.blocks[i].m_height; // Return the area of the pillar
      }
    }
  }
  
  return 0; // No pillar detected
}

// Turn Functions
void turnLeft() {
  targetYawAngle += 90; // Adjust angle to the left
  int c = 0;
  while (c < 1500) {
    MoveFWwithGyro();
    c++;
  }
}

void turnRight() {
  targetYawAngle -= 90; // Adjust angle to the right
  int c = 0;
  while (c < 1500) {
    MoveFWwithGyro();
    c++;
  }
}
